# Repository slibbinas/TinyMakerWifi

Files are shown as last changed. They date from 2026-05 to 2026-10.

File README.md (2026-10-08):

# TinyMakerWifi

Modified and extended firmware for the open-source **TinyMaker** MSLA resin 3D printer. The main additions: **WiFi connectivity**, **OTA updates**, and **direct model upload from PrusaSlicer** - no more SD card shuffling.

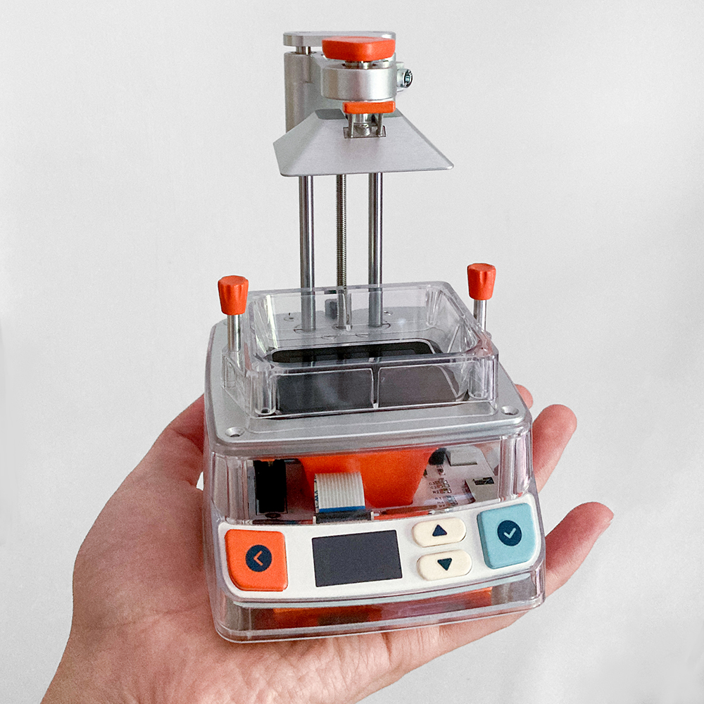
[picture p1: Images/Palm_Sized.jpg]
TinyMaker palm-sized resin 3D printer


🌐 **[tinymakerwifi.com](https://tinymakerwifi.com)** - the project site: what the firmware does, how to get started, community links and an *Open my printer* shortcut.

🧪 **[Live demo](https://tinymakerwifi.com/demo/)** - the real web dashboard driving a simulated printer: start a print, watch the 3D progress, poke through Settings. Nothing to install, no printer needed.

📖 **[Illustrated user manual](https://slibbinas.github.io/TinyMakerWifi/manual/)** - step by step from the first flash to Home Assistant, with screenshots and an FAQ. Also one tap away from the printer's dashboard (the *Manual* link in the header).

📝 **[Changelog](CHANGELOG.md)** - what each version added and who contributed it, in plain language.

💬 **[Feedback](https://tinymakerwifi.com/feedback/)** - what works, what doesn't, what's missing. Photos welcome, no account needed; the dashboard header links it too.

## Features

* **WiFi setup via captive portal** - no credentials in code, configured from your phone on first boot
* **Direct upload from PrusaSlicer** ("Send to printer" button) - the printer emulates the Prusa SL1 network protocol
* Automatic unpacking of uploaded `.sl1` / `.zip` files into the layer format the stock firmware expects (works with both PrusaSlicer and UVtools numbering). A model sliced for a different printer - layers wider than the 320 px screen - is refused with a *re-slice it for TinyMaker* message, on the printer and in the dashboard, instead of being started
* New **System** menu on the printer: WiFi Info (SSID, signal, IP, reset), **Advanced** settings, **Statistics**, firmware Update, About
* **Advanced menu on the printer** - screen timeout, dry run, the resin-tracking controls (Set VAT full, low-resin pause, warn threshold, ask-refill) and **WiFi / Web control on-off switches**, all without a computer *(contributed by [@Briadark](https://github.com/Briadark))*
* WiFi status indicator (green/grey dot) on the main menu
* **Model deletion from the printer** - long-press OK on a model in the Print menu
* **Import from SD card** - copy an `.sl1`/`.zip` onto the card and it shows up in the Print menu (in blue); press OK to convert it into a printable model. Works without any network, the archive is removed after a successful import
* **Lifetime print-hours & UV LED hours counters** - the System → Statistics screen shows total printing time and total LED-on time (the LED ages by lit time; dry runs don't count). Stored in NVS, survives firmware updates
* **Settings backup & restore** - one file holds every setting and the lifetime counters: download it, keep it on the SD card, and after a full USB reflash the printer offers to restore everything on first boot. The dashboard shows the SD backup's date, has a one-click **Restore from SD**, and can optionally **auto-backup to TinyMaker Connect** *(contributed by [@Briadark](https://github.com/Briadark))*
* **Boot update check** - shortly after WiFi connects at boot the printer checks for new firmware and offers *Install / Later* right on the screen (switchable) *(contributed by [@Briadark](https://github.com/Briadark))*
* **Boot animations** - pick the animation the printer plays at power-on (System → Advanced, or staged in the dashboard and applied with *Save config*), preview it with **Show** right on the printer's screen, install new ones one-click from the **Default library** or the community site, or **Shuffle** a random one each boot *(base contributed by [@Tann2019](https://github.com/Tann2019))*
* **Exposure calibration test** - cures an 8-bar test strip straight from the printer (System → Advanced), each bar a different exposure; no slicer or SD file needed
* **Clean Resin Vat** (Maintenance) - full-screen UV exposure cures a thin skin over the vat so debris lifts out in one piece (stock TinyMaker feature, kept and counted into LED hours)
* **Named resin profiles** - one resin, one recipe: layer height, both exposures, base and transition layers, all four lift settings, and the resin’s density with its weighing calibration. Switching resin is one press instead of ten fields. Four profiles are **built into the firmware** - two resins at both layer heights, `Fast fine` / `Fast draft` and `Slow fine` / `Slow draft` (so the list is never empty - no SD card, no network, after a factory reset). The two `Fast` profiles ship with a weighing calibration measured on this printer - a multiplier plus about 0.6 ml of film that stays on the plate each print - while the `Slow` pair starts uncalibrated until you weigh a print. A **library of ready-made profiles** can be installed from the picker; a “✓ tested by” badge means someone actually printed with that resin on this printer. Pick the resin from the dashboard’s main view, from Settings → Print, or at the machine under System → Advanced → Resin
* **Resin usage estimate** - press UP on the print preview to estimate the resin a model needs - shown in ml AND in vat fills (e.g. `12.4 ml = 0.8 VAT`; vat size adjustable 10–40 ml in Settings, default 15). Live ml is shown while printing
* **Resin level tracking** - the printer keeps an estimate of how much resin is left in the VAT, warns before starting a print with too little, and can optionally pause mid-print for a refill (see [Resin level & refills](#resin-profiles-level--refills))
* **Model preview in the dashboard** - click any SD model: the browser rebuilds the shape from the sliced layers and draws it in the **Model preview** card as a smooth, GPU-rendered 3D model (three.js, cached on the SD card - falls back to the built-in renderer without it), with a compact info line (layers, height, time, resin) and a quick `~ml` resin estimate - click it to run the exact scan. The card's title names the model it is showing and is a link back to it in the SD list - including while printing, when the title reads *Printing 42% · Tooth*
* **Slice in the browser** - the dashboard slices STL files itself, on by default: choose an STL (or drag it onto the slicer block), get supports and a raft, preview the result in 3D and 2D/UV, and send it to the SD card ready to print. The slicer module is fetched once, kept on the SD card (survives firmware updates, works offline afterwards) and every byte is verified against checksums the printer fetches over certificate-checked HTTPS
* **Safe model uploads** - uploads unpack into a temporary folder and replace the old model only after unpacking succeeds; a name conflict asks *Replace / Rename / Cancel* (PrusaSlicer re-uploads just replace) *(contributed by [@Briadark](https://github.com/Briadark))*
* **3D print progress** - while printing, the dashboard shows the same 3D view filling up in real time: the printed part in color, the rest as a ghost outline. Zero load on the printer (the browser renders from prefetched layers)
* **WiFi reset** - from the System menu, or by holding the BACK button while powering on
* **Web dashboard** - open the printer's IP in a browser: SD manager (upload - or drag an `.sl1`/`.zip` onto it - delete, start), live print status with pause/resume/stop and finish-time estimate, device config and a dry-run test mode - with a **light / dark / system theme**, a dismissible **Getting Started** checklist, contextual **?** help next to the tricky settings, an always-on **Model preview** card (remembers the last previewed model) and a **PWA manifest** so the dashboard pins to a phone's home screen with the project icon. While a print runs, the slicer and SD cards fold to their headers and stay locked until it ends *(initial version contributed by [@Briadark](https://github.com/Briadark))*
* **Power-loss resume** - a checkpoint on the SD card lets the printer pick a print back up after an outage instead of starting over, or safely lift the plate off a stuck print (up only, never into the vat). Answer the prompt at the printer **or from the dashboard on your phone** - a first for a resin printer in this class *(checkpoint engine contributed by [@Tann2019](https://github.com/Tann2019))*
* **MQTT / Home Assistant** - optional integration with auto-discovery: print state, layers, resin used, **resin left + low-resin alert**, run/remaining time as HA sensors
* **Telegram, WhatsApp or Discord notifications** - the printer messages you when a print **finishes** (with time and resin used), **pauses for low resin**, is **canceled**, or when **power comes back** after an outage interrupted a print. Pick one channel: a Telegram bot, WhatsApp through the free CallMeBot gateway, or a Discord channel webhook - each with inline **?** setup help and a *Send test* button. *(Telegram is tested daily; WhatsApp and Discord ship untested - they ride on your own CallMeBot key or channel webhook, so the only test that proves anything is yours. Reports welcome, working or not.)*
* **TinyStatus watch app** - a separate Wear OS app, [TinyStatus](https://github.com/slibbinas/TinyStatus), puts time left, the layer, resin left and a progress ring on your wrist and watch face, and buzzes when a print ends or the resin runs low. It only reads - see [On your wrist: TinyStatus](#on-your-wrist-tinystatus)
* **Anonymous usage ping and crash reports** (optional) - once per firmware version the printer sends a one-way hash of its MAC address, the firmware version and the lifetime print hours, so we know how many printers are out there. If it restarts unexpectedly or dies in the middle of a print, it also sends a short crash report: the same hash, the firmware version, why it restarted, the layer the print stopped at and roughly when, and - after a crash - the program addresses where it happened plus a fingerprint of the exact firmware build, so the fix can find the line. No models, settings or network details, ever - switch both off under Settings → Network → *Anonymous usage ping*
* **Firmware updates over WiFi** - self-update from the printer (System → Update) or from the dashboard's **Settings → Update** pane (install latest, pick **any version** from a list, or upload a file). Self-update follows the stable channel; betas are offered only in that version list, so no printer installs one by itself. PlatformIO OTA for developers. Flashing is blocked while printing.
* Everything is switchable: WiFi and Web control can be turned off right on the printer (System → Advanced), and build switches still let developers compile the original, network-free firmware from the same code base

## Screens

The small status display drives the whole UI - first-boot WiFi setup, wireless upload, resin estimate and guarding, device toggles, and self-update:

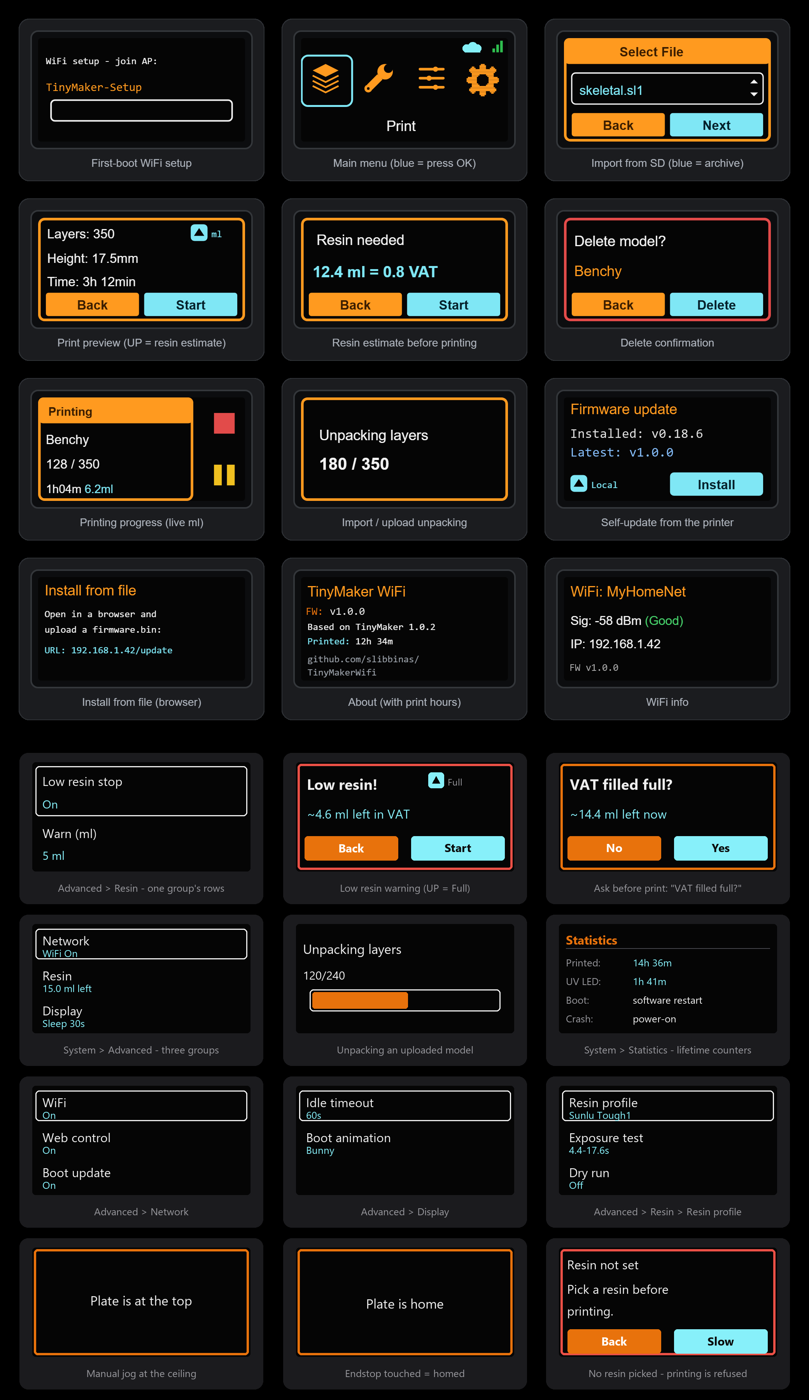
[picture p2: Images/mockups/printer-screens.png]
TinyMaker WiFi - printer UI screens


## Hardware

Stock TinyMaker electronics - **ESP32-WROOM-32E-N4** (4 MB flash, no PSRAM). No hardware modifications required; WiFi is already on the module.

## Installing the firmware

Three ways to get the firmware onto the printer - the first is by far the easiest.

### Method 1: Web flasher (recommended)

**[connect.tinymakerwifi.com/flash.php](https://connect.tinymakerwifi.com/flash.php)** flashes the latest release straight from your browser - nothing to download or install *(contributed by [@Briadark](https://github.com/Briadark))*:

1. Connect the printer to your computer via USB.
2. Open the web flasher in **Chrome or Edge** (they support Web Serial; Firefox/Safari don't).
3. Click **Connect** and select the printer's serial port (unsure which? unplug/replug the USB cable and watch which entry appears).
4. Flash - the tool fetches the latest release itself. Power cycle the printer when it finishes.

If your computer does **not** recognize the printer over USB, install the CH340 driver from the `Driver` folder of this repository (`CH341SER.EXE`), then try again.

#### Flashing fails with `ERROR: Timeout`?

If the flasher connects, downloads the firmware and then dies partway through **Writing firmware-full.bin**, the transfer speed is almost always the culprit - not the browser:

1. **Lower the baud rate.** The **Baud rate** dropdown on the flasher page defaults to `921600`. Set it to **115200** and flash again. It takes a few minutes instead of ~30 seconds, but it tolerates marginal cables and USB-serial chips far better.
2. **Swap the USB cable.** Charge-only cables and cables with thin data lines are the second most common cause. Use a short, known-good data cable.
3. **Plug straight into the computer**, not through a hub, dock, monitor or keyboard port.
4. **Update the CH340 driver** (see above) - an old Windows-bundled driver produces exactly this symptom.
5. **Several ports in the picker?** Unplug the printer, reopen the port picker, plug it back in, and choose the entry that appears.

Still stuck after all five? Open an [issue](https://github.com/slibbinas/TinyMakerWifi/issues) with the flasher log and the baud rate you used.

### Method 2: Already running TinyMakerWifi? Update over WiFi

No USB needed - use `System → Update` on the printer or the dashboard's **Settings → Update** pane. See [Wireless Firmware Updates](#wireless-firmware-updates).

### Method 3: Manual flashing (fallback & developers)

Download the latest **`firmware-full.bin`** from the [Releases](https://github.com/slibbinas/TinyMakerWifi/releases) section of this repository.

> ⚠️ **Which file do I need?** Releases contain two files and they are NOT interchangeable:
>
> | File | Used for | How |
> |---|---|---|
> | **`firmware-full.bin`** | **First-time USB flashing** (this section) | USB flash tool, address **`0x0`** |
> | `firmware.bin` | Wireless updates **only**, after this firmware is already installed | Browser, `http://tinymaker.local/update` |
>
> Flashing `firmware.bin` over USB will **not** work correctly: it lacks the bootloader and partition table, so the printer either won't boot (if flashed at `0x0`) or OTA updates will be broken (if flashed at `0x10000` over the stock firmware).

**Option A: generic web esptool** - [https://esptool.spacehuhn.com/](https://esptool.spacehuhn.com/) in Chrome/Edge: click **Connect**, pick the port, **remove all pre-filled entries**, click **ADD**, upload your **`firmware-full.bin`** with its address set to **`0`**, then **Program** and power cycle.

**Option B: Espressif Flash Download Tool (Windows)** - if you prefer the official desktop tool:

1. Get **`flash_download_tool.zip`** from the `Flash_Installer` folder of this repo (or the official [Espressif Flash Download Tool](https://docs.espressif.com/projects/esp-test-tools/en/latest/esp32/production_stage/tools/flash_download_tool.html) page). **Extract the ZIP fully before running.**
2. Run the extracted `flash_download_tool_xxx.exe`.
3. In the "Download Tool" window, select **ESP32** and **Develop** mode.
4. Configure the settings **exactly** as follows (wrong settings are the most common cause of a non-booting printer):
    * **SPI Speed:** 40 MHz
    * **SPI Mode:** DIO
    * **Flash Size:** 32 Mbit (4MB)
5. Click the three dots `...` next to the first row and select **`firmware-full.bin`** (not `firmware.bin`!).
6. In the address field next to the file, enter **`0x0`** (zero - not `0x10000`).
7. Ensure the checkbox on the left of the file path is **checked** - without it the tool flashes nothing and still reports success.
8. Select the correct **COM port**, click **START**, and power cycle the printer when it says "FINISH".

Note: the first boot after flashing may take a few seconds longer than usual, and the printer will start the `TinyMaker-Setup` WiFi access point (see below). Printer settings (exposure, layer height, etc.) reset to factory defaults.

## First WiFi setup

1. Power on the printer. On first boot it starts a **`TinyMaker-Setup`** access point.
2. Connect to it with your phone - a captive portal opens automatically (or browse to `http://192.168.4.1`).
3. Select your home WiFi network and enter the password.
4. The printer connects and briefly shows its IP address; credentials are stored, so next boots connect automatically (~5 s) - animated signal bars on the boot screen turn green when connected. If the saved network is unreachable, the printer simply boots in offline mode after 15 s - printing from SD works as always.

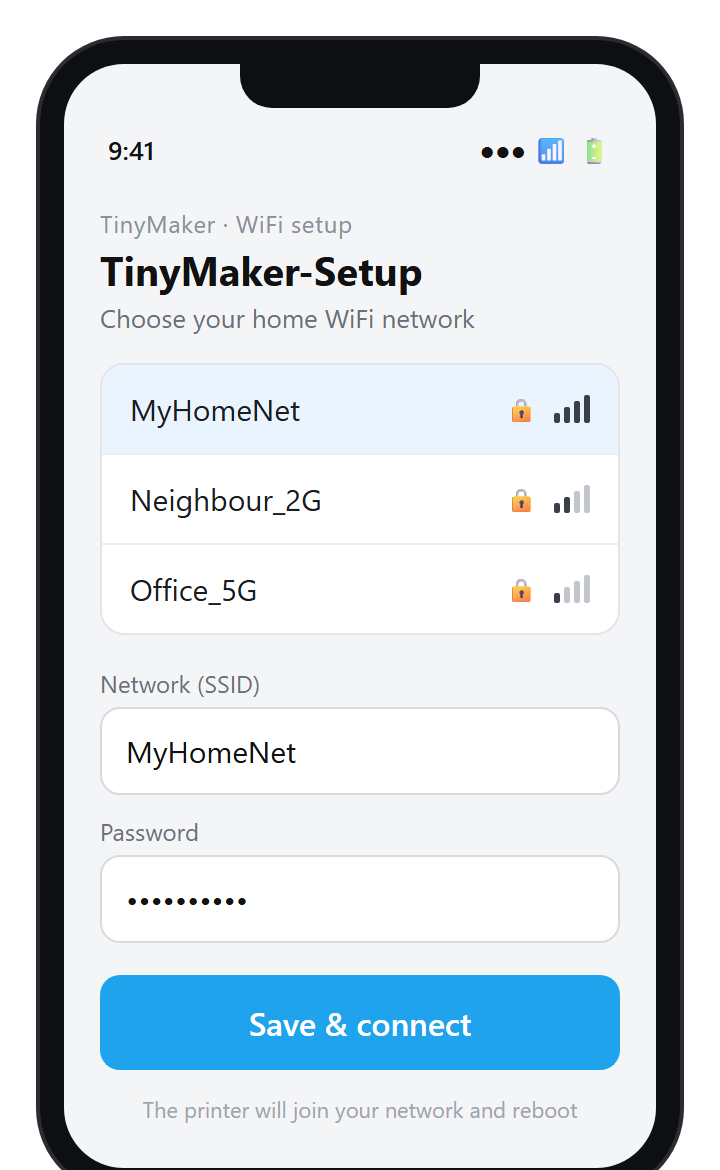
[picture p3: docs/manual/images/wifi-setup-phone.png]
TinyMaker-Setup captive portal as seen on a phone


WiFi status, signal strength and IP are always visible under **System → WiFi Info**.

### Resetting WiFi

Two ways to erase the stored credentials (e.g. when moving the printer to another network):

* **From the menu:** System → WiFi Info → press OK → confirm. The printer erases the credentials, reboots and starts the `TinyMaker-Setup` portal again.
* **Emergency reset:** hold the **BACK** button while powering the printer on. Use this if the printer keeps trying to connect to an old network and you can't reach the menu in time.

## PrusaSlicer setup

1. Import the TinyMaker printer profile (`TinyMaker.ini`, in this repo) via *File → Import → Import Config*.
   **Then save each of the three presets** - click the floppy-disk icon next to *Print settings*, *Material* and *Printer* and accept the names. Imported presets are temporary until saved, so without this step PrusaSlicer forgets the printer every time you close it, and you start over.
2. Add a **physical printer**: click the cog icon next to the printer profile → *Add physical printer*:
   * **Name:** anything (e.g. `TinyMaker WiFi`)
   * **Hostname, IP or URL:** `tinymaker.local` (or the printer's IP shown in System → WiFi Info)
   * **API Key:** any text (not verified)
   * Note: The printer emulates the Prusa SL1 network protocol.
3. Click **Test** - it should report a successful connection (printer must be on and connected to WiFi).
4. Slice and press **Send to printer**. The printer shows *Receiving → Unpacking → Model ready*, and the model appears in the **Print** menu.

<p>
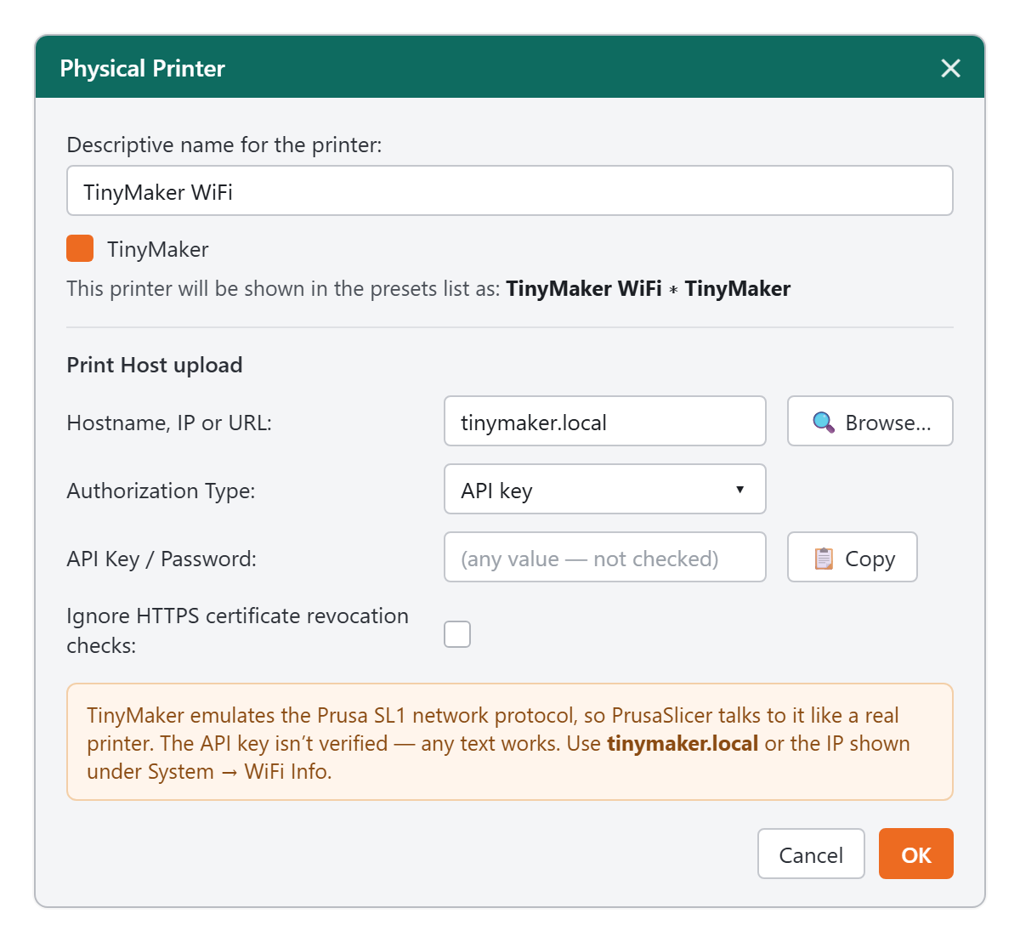
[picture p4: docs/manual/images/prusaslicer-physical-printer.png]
PrusaSlicer: add a physical printer pointing at tinymaker.local with API key auth
  
  &nbsp;
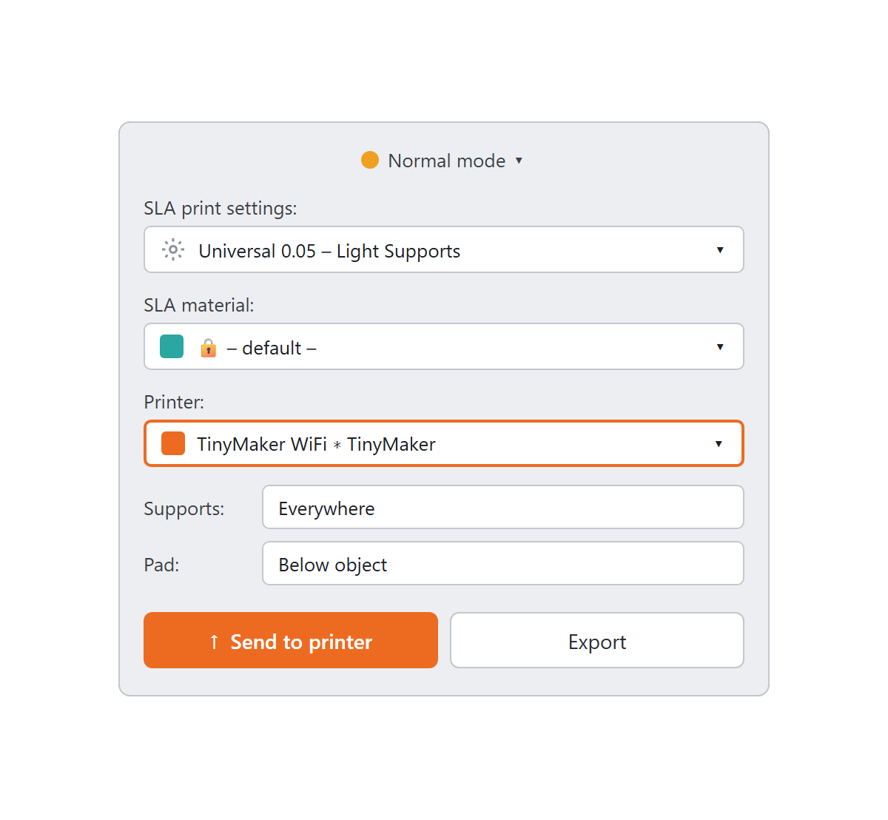
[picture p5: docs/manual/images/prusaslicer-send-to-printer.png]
PrusaSlicer: select the TinyMaker WiFi printer and press Send to printer
  
</p>

**Always slice with the 0.05 mm profile.** Unlike FDM, the printed layer height is set **on the printer** (Settings → Layer Height), not by the sliced file - the file is just a stack of 0.05 mm images, and at the 0.10 mm printer setting the firmware takes every other image. Maximum model size: 1200 layers = 60 mm. If prints come out **flat or the wrong height**, check that PrusaSlicer's *Print settings* still show **0.05 mm** - an update or the wrong preset can silently reset it, and the printer can't detect it from the file.

## Slice in the browser

No slicer installed, and nothing to install: the dashboard slices STL files itself, and since
0.17.6 it is on from the start - the **STL slicer** card is right there on the dashboard. (It
can be switched off under Settings → Network → *STL slicer in the dashboard*.) Choose an STL, let it stand the right way up, then press **Slice**.

Two switches decide how the slicer places the part on its own. **Fit by:** *flat* lays it on
its widest side, *supports* searches for the rotation that needs the fewest supports, the way
PrusaSlicer does. **Size:** *keep* leaves your size and scales down only when the part does not
fit, *max* makes it as large as the plate allows, up to 300 %. The **Fit** button on the 3D view
puts the part back the way the two switches say; **Lay flat**, **Flip over**, **Tilt 90** and
**Rotate 90** are there when you want to decide yourself.

Below sit six more settings, and **Reset to defaults** puts them all back (Fit by and Size
included): **Supports** (regular or tree), **Strength**, **Placement**, **Tip**, **Raft layers**
and **Smoothing**.
The raft is counted **in layers, not millimetres**. The file is always sliced at 0.05 mm and
the printer decides how many of those images to expose, so the same setting means different
millimetres at a different layer height. The default is **3 layers**; the choice is 2, 3 or 6.
One layer is not offered any more - the pad does not bond to the part at all. Measured here:
a printed pad comes out about 0.15 mm thicker than asked, so 3 layers lands on the ~0.3 mm a
PrusaSlicer plate gives and lifts off with a spatula without force. A thicker raft costs
resin, not time - unless the part is lifted off the plate: then it adds layers too.

You get the result before anything is sent anywhere: the part on its raft in 3D, layer by
layer in 2D, and the numbers that matter underneath - size, triangles, layer count, supports
and the resin estimate. **Send to printer** then puts it on the SD card, ready to print;
**Discard** throws it away and costs nothing.

The slicer is a **module the printer keeps on its own SD card**: fetched once from our GitHub
Pages, verified byte-for-byte against checksums, and used from the card afterwards - so it
works with no internet and survives firmware updates. Everything is sliced at 0.05 mm, the
same as every other model here.

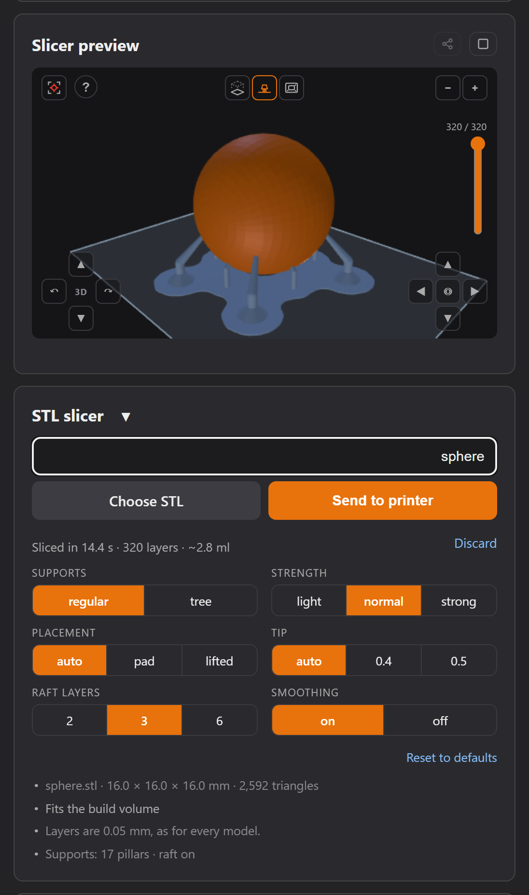
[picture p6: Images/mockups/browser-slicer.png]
A model sliced in the browser: the preview shows the part in orange standing on its raft with 180 support pillars in blue, and the slicer card reports the time, the layers, the resin and the supports it added


## Importing models from the SD card

No network? Copy an `.sl1` or `.zip` (exported by PrusaSlicer/UVtools) into the **root** of the SD card. It appears in the **Print** menu in **blue** among the models - press **OK** to convert it (progress is shown). When done, the new model appears in the list and the archive is deleted from the card. Long-press OK on a blue entry deletes the archive without importing.

## Deleting uploaded models

In the **Print** menu, **press and hold OK for ~1.5 seconds** on a model - a *Delete model?* confirmation appears (release the button first, then **OK = Delete**, **Back = No**). Deletion removes the whole model folder from the SD card and shows a progress bar (large models take a while - hundreds of layer files). A short OK press starts printing as usual.

## Web dashboard

Open the printer's IP address in any browser for the full dashboard *(initial version contributed by [@Briadark](https://github.com/Briadark))*: live print status and controls, SD card management with one-click start/import, device settings, backups and firmware updates - all in tabs styled to match the printer's UI.

In a narrow window - a phone, or half a screen - everything is one column:

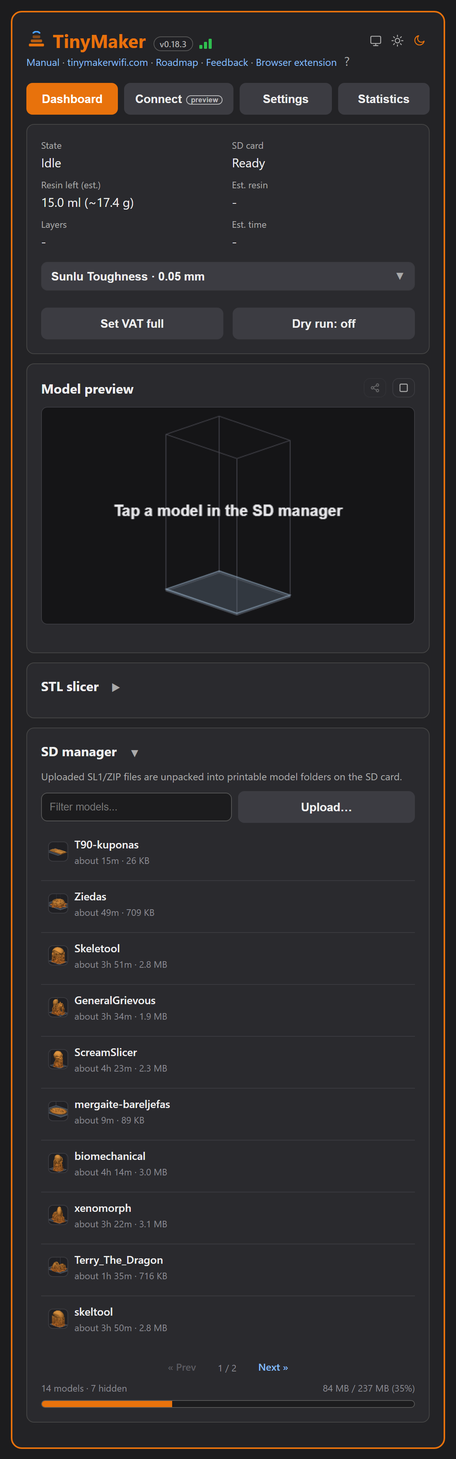
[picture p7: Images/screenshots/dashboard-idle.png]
The dashboard in a narrow window: one column, with the status card, the model preview and the SD manager stacked


On a desktop-sized screen it spreads into two columns:

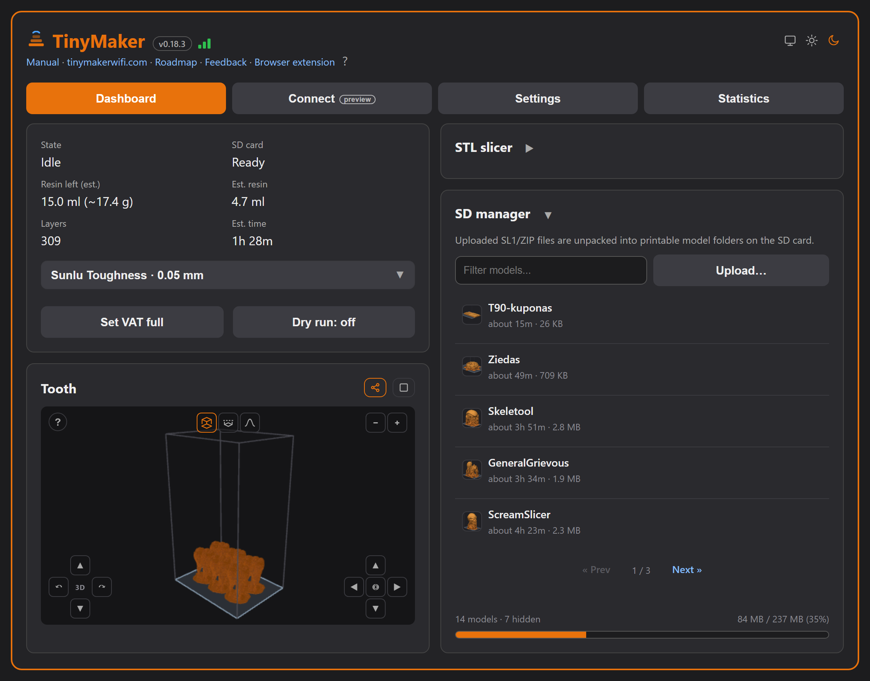
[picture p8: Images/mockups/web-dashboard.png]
The dashboard on a wide screen: two columns, with status and model preview on the left, the STL slicer and SD manager on the right


While a print runs, the status card counts the current phase down next to its name - *Curing · 9s* - and a small dot says whether the printer answered just now or is mid-move. That matters on this hardware: one ESP32 drives the screen, the motor, the UV LED and the web server off a single SD card, so the dashboard is served in the gaps between layer moves. A pause of a few seconds with an amber *syncing* mark is the printer working, not the page hanging. How long the dashboard waits follows the print (the longest exposure plus 10 seconds); if your phone or laptop reaches the printer through a slow link such as a WiFi extender, give it more time under **Settings → Network → Wait while printing** - the value is kept in that browser only.

### 3D preview & live print progress

Every model on the SD card can be previewed in 3D - the browser rebuilds the shape from the sliced layers (the printer only streams a few dozen small files) and draws it inside the build-volume box. Start the print from the dashboard and the same view turns into a **live progress render**: the printed part fills in with color, the unprinted rest stays a ghost outline. It costs the printer nothing while printing.

There is no mesh to render - the model reaches the printer already sliced into images, so the shape is rebuilt from the layers themselves. The smooth surface comes from three.js on the GPU; the library is fetched once and then lives on the SD card, so the preview keeps working with no internet. Without the library (or on a browser without WebGL) a built-in canvas renderer takes over: only the surfaces the camera can actually see are drawn, each shaded from a normal estimated out of its neighbourhood, which is what makes blocky voxels read as a rounded object.

A real print in progress - a plate of teeth with supports, rendered live in the build-volume box:

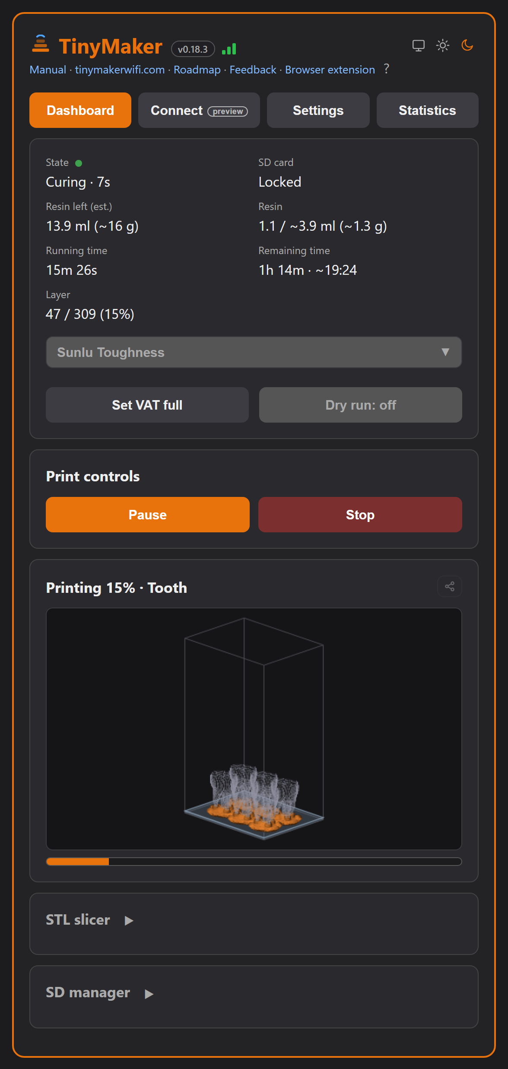
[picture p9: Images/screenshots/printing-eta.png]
Real dashboard screenshot while printing: status with finish-time estimate, print controls and the live 3D print progress render


## Advanced menu (WiFi and Web control switches)

**System → Advanced** on the printer *(contributed by [@Briadark](https://github.com/Briadark))* holds the device toggles - OK changes a value, Back returns:

Since 0.16 the items sit in **three groups** - Network, Resin and Display - so the list stays
short at every step, and each group row shows its own state at a glance (`WiFi On`,
`15.0 ml left`, `Sleep 60s`).

**Network**

| Item | What it does |
|---|---|
| **WiFi** | **On/Off - the whole network** (web, PrusaSlicer upload, MQTT, self-update) |
| Web control | On/Off - browser **actions**. Off = the dashboard turns view-only (watch, but no print control, SD changes, uploads or firmware updates) |
| MQTT | On/Off (shown once MQTT is configured in the dashboard) |
| Boot update | On/Off - whether the printer checks for newer firmware shortly after it connects |

**Resin**

| Item | What it does |
|---|---|
| Resin profile | Steps through the installed profiles and applies the one shown - the whole recipe for that resin |
| Set VAT full | Press after a **full** refill - restarts the level estimate from a full VAT; it does not measure what you poured |
| Low resin stop | On = mid-print, at *Stop (ml)*, the printer finishes the layer, lifts and pauses for a refill. On by default: below the stop level the VAT floor goes dry |
| Stop (ml) | The level that stops the print: 3 - 4 - 5 - 6 - 7 - 8 ml (OK cycles), default 4. Three is this VAT's measured floor, not a preference |
| Warn (ml) | The earlier heads-up, on the screen and on your phone: 5 - 6 - 7 - 8 ml, default 5. Keep it above the stop level |
| Ask refill | On = every print starts with a "VAT filled full?" question (Yes resets the estimate to a full VAT, so answer yes only after a full refill) |
| Power resume | On = the printer checkpoints as it prints and offers to resume after a power cut |
| Resume mode | **Balanced** checkpoints every 800 ms of plate movement, **Precise** every 400 ms |
| Pause lift | How high the plate rises when you pause to look at the print: 20-40 mm in 5 mm steps |
| Exposure test | Cures an 8-bar calibration strip around your Regular exposure - resin in the vat, no build plate |
| Dry run | Test prints without UV - motion and display only (the UV stays off *everywhere*, the vat-cleaning cycle included) |

**Display**

| Item | What it does |
|---|---|
| Idle timeout | Blank the status screen after 30 s...10 min of inactivity (Off = never). Only while idle - never mid-print |
| Boot animation | Which animation plays at power-on |

How the network switches behave:

* **WiFi Off** makes the printer fully offline, like the original firmware. Toggling WiFi asks *"Reboot now?"* - OK reboots and applies it immediately, Back applies it on the next power-up. Everything network-related disappears from the menus until WiFi is back on - **turning it back on is done right here (System → Advanced → WiFi)**, no reflash or reset needed.
* **Web control Off** makes the dashboard **view-only**: anyone on the network can still open it and watch the print (status, layers, resin left, SD contents, model details), but every action - print stop/pause, SD delete/upload, resin estimate, settings, Set VAT full, firmware updates - is disabled with a clear banner. PrusaSlicer/UVtools "Send to printer" and MQTT/Home Assistant keep working. Turning it back on is done on the printer (System → Advanced), since the settings form is among the things it locks.
* If WiFi is off and you open **System → Update**, the printer offers to enable WiFi temporarily just for the update.
* WiFi and Web control are also in the dashboard's Settings tab (with a confirmation - unchecking Web control locks you out of settings until it is re-enabled on the printer, and turning WiFi off from the browser reboots the printer).

Both switches default to **On**, and stay On after upgrading from an older version - nothing changes until you change it.

## Resin profiles, level & refills

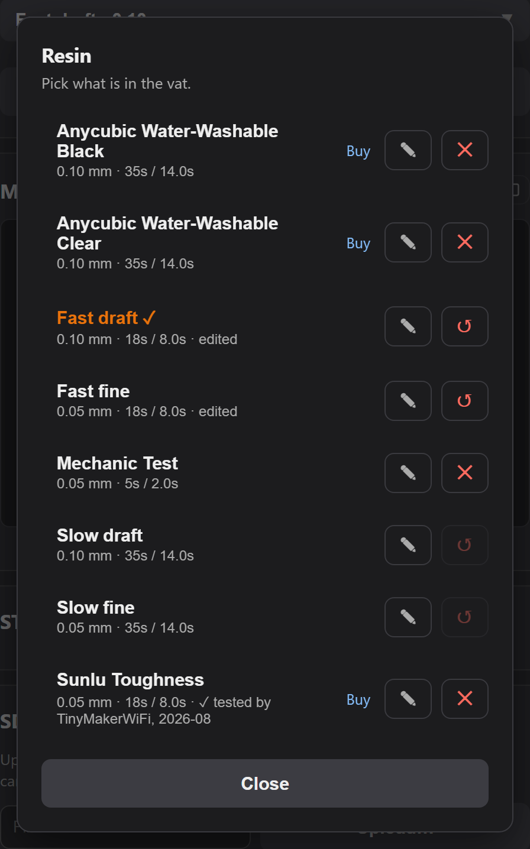
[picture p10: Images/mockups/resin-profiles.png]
The resin picker: built-in and installed profiles, one marked tested by with a Buy link, and a line offering ready-made profiles to install

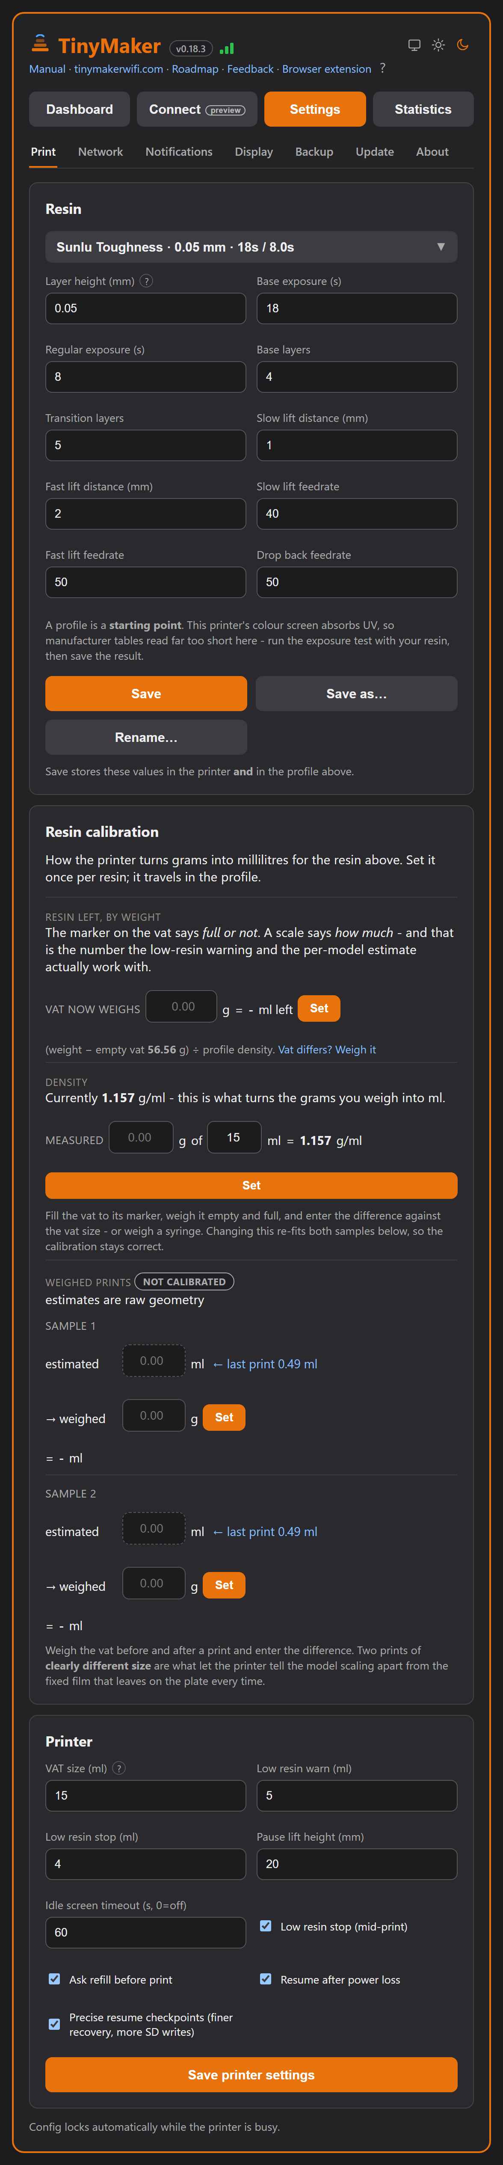
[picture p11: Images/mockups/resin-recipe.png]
Settings, Print tab: the selected profile with its whole recipe - layer height, exposures, layers and the four lift settings - then Save, Save as and Rename, and the resin calibration by weight


The printer has no resin sensor - instead it **keeps count**: every printed layer's cured volume (the same white-pixel estimate used for the ml counter) is subtracted from the VAT level. The estimate survives reboots and firmware updates.

* **"Resin left (est.)"** is shown on the dashboard; in Home Assistant it appears as a *Resin left* sensor plus a *Resin low* alert you can automate notifications on.
* **After a full refill**, tell the printer: **System → Advanced → Set VAT full** on the printer, or the **Set VAT full** button on the dashboard - it works while printing too. The estimate restarts from a **full** VAT (your VAT size setting): it does not measure what you poured, so fill it to the top. Pouring less leaves the printer believing it has more resin than it does.
* **Ask refill** (default On): every print begins with a *"VAT filled full?"* question - on the printer (OK = yes / Back = no) and in the browser - so the estimate stays honest even if you forget the button. Tidy users can turn it off (System → Advanced or dashboard Settings); the low-resin warning screen then still offers **UP = Full** as a shortcut.
* **While printing** the dashboard shows resin like layers: `used / ~total ml` (total = the fresh estimate when you ran one, otherwise a running average) plus *Resin left (est.)* in the VAT.
* **Before a print starts**, if the level is at/below the warning threshold (or a fresh ml estimate says the model needs more than what's left), the printer shows **"Low resin!"** with the numbers - Start anyway or Back. Starting from the browser asks the same in a dialog.
* **Low resin pause** (default On): mid-print, when the level drops to the threshold, the printer finishes the layer, lifts and pauses showing **"Fill VAT full!"** - do a full refill, press Set VAT full, then resume. Resume stays locked until the refill is marked, and only Stop works meanwhile; on the printer itself, confirming *"VAT filled full?"* marks it and resumes. The threshold (`Stop (ml)`, 3–8 ml, default 4) is set on the printer (System → Advanced) or in the dashboard's Settings tab.
* **Roughly 4 ml of every filling cannot be printed with.** The VAT is 42 × 52 mm inside, so a millimetre of resin is about 2.2 ml and a full 15 ml VAT is under 7 mm deep. Poured resin stops covering the whole floor at about 4 ml, and it clings to the walls, so the middle can open a dry patch a little above that. That is why the stop level cannot be set below 3 ml, and why a 15 ml VAT gives about 11 ml of printing per filling.

> ⚠️ It is an **estimate**, not a measurement - it doesn't account for resin sticking to models or drips, so treat it as a planning aid and glance at the real VAT now and then. Refills you don't confirm with "Set VAT full" won't be counted.

## On the browser toolbar: TinyMaker status (Chrome extension)

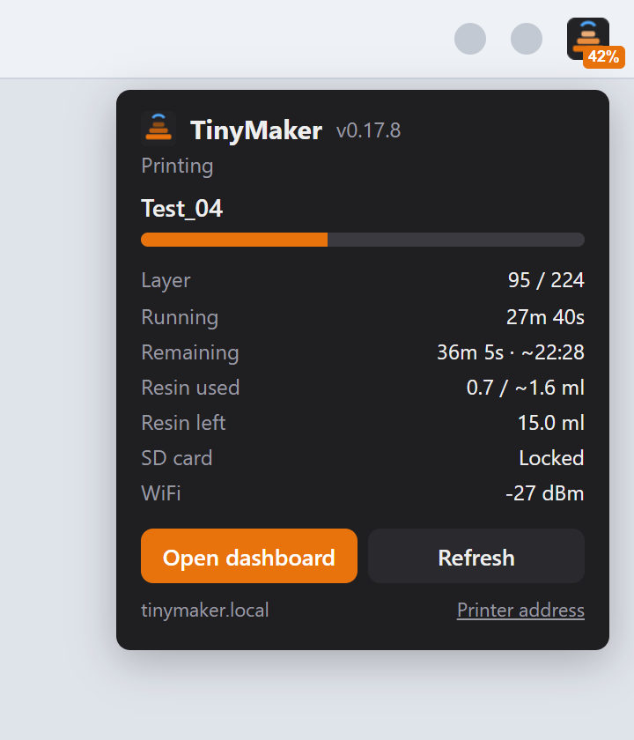
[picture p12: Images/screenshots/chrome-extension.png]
TinyMaker status extension: 42% on the toolbar icon and the popup with the print's layer, times and resin


A small Chrome extension puts the printer on the browser toolbar: the icon shows the print
progress (`42%`), `II` when paused, `SD` while the card is busy, a tick when a print has just
finished and `!` when the printer does not answer. Click it for the state, model, layer,
time left (with the finishing time), resin used and left, and a button that opens the
dashboard - or switches to it, if it is already open in a tab. It only reads the printer's status once a minute - it never changes anything.

**[Install it from the Chrome Web Store](https://chromewebstore.google.com/detail/tinymaker-status/bhfjpfjkhopfnfpapgahmaipdgmajlde)** - one click, and Chrome keeps it updated.

1. **Add to Chrome.** Its options page opens by itself.
2. Enter the printer's address - the same one you open the dashboard with (the printer shows
   it on the idle screen and under **System -> WiFi Info**), or `tinymaker.local` - and press
   **Save**. Chrome asks to let the extension read that one address: **Allow**.
3. Pin it so the icon stays on the toolbar: the puzzle icon at the top right -> the pin next
   to **TinyMaker status**.

Had the earlier zip installed by hand? Remove it in `chrome://extensions` first, otherwise you
get two icons. For the first months Chrome may call it *not trusted by Enhanced Safe Browsing* -
every new developer starts like that, and it clears on its own. Tested in Chrome; Edge has not
been tried yet.

## On your wrist: TinyStatus

<p align="center"><a href="https://github.com/slibbinas/TinyStatus">TinyStatus on a Wear OS watch showing the printer's status</a></p>

**[TinyStatus](https://github.com/slibbinas/TinyStatus)** is a Wear OS app that shows what
this printer is doing without reaching for a phone: time left, which layer, how much resin
is still in the VAT, and a progress ring. It can watch a print in the background and buzz
your wrist when the print ends or the resin runs low, and it can put those numbers on your
**watch face** as complications.

It is **not firmware** - it installs on the watch, not on the printer, and it only reads.
It sends no commands, so it cannot start, pause or cancel anything.

* **Download:** [latest release](https://github.com/slibbinas/TinyStatus/releases/latest)
  (`tinystatus-<version>.apk`). Not on Google Play, so it is **sideloaded** - the release
  notes walk through it from a phone (no computer needed) or over `adb`.
* **You need:** a Wear OS 4+ watch, the watch and the printer on the same Wi-Fi, and
  firmware **0.16.2 or newer** - that is what it has been tested against. Two fields
  arrive with **0.17.0**, and without them the app gets less precise rather than
  breaking: telling a cancelled print apart from a finished one falls back to the state
  code alone, and the low-resin warning uses the default 5 ml instead of the level you
  picked.
* **Several printers:** up to four by IP, swipe sideways to switch.
* **What it costs the printer:** `GET /api/status` every 5 s while the app is open, and
  nothing at all when it is closed - unless background watching is on, and then every
  30 s to 10 min (your choice) **only while a print is running**, stopping by itself
  20 minutes after it ends. `/api/config` is read once a day. No writes.

It lives in its own repository with its own releases, because it is an Android project and
this one is PlatformIO. If you are building something else against the printer, the API it
uses is documented in [docs/api.md](docs/api.md) - and the fields it reads are listed there
as a known consumer, so they will not be renamed out from under it.

## Wireless Firmware Updates

> 🔒 Firmware flashing is **blocked while the printer is printing**, and the web paths require **Web control** to be on. (Model upload from PrusaSlicer is separate - it works any time.)

Three ways to update:

* **On the printer (self-update, no computer):** `System → Update` shows the **installed** version and checks GitHub for the **latest**. If a newer one is available, the `Install` button lights up - press **OK** and the printer downloads and flashes it itself over WiFi.
* **From the dashboard - the Update tab:** shows installed vs latest with an **Install latest** button, a **version picker** (install any released version, downgrades ask for confirmation) and **Choose & flash…** for a `firmware.bin` file from [Releases](https://github.com/slibbinas/TinyMakerWifi/releases) or a local build.
* **For developers:** PlatformIO OTA - open `System → Update` on the printer (this path keeps the strict screen gate), then select the `env:tinymaker-ota` environment and Upload goes over WiFi.
* **The browser slicer updates separately.** As long as the slicer is on, the same Update tab holds a **Slicer module** card - the version on the printer’s SD card vs the latest published, with its own install button and version picker. A slicer update copies a few megabytes to the card; the printer never reboots for it, and a running print is never interrupted.

Every release carries our own signature. Before an update from the internet is installed, the printer checks that signature against a key built into its firmware and activates the download only if it matches byte for byte - so it no longer matters which certificate GitHub shows in your region or what the printer's clock says. If the check fails, nothing is installed and the printer says the update was refused. **Choose & flash…** (a file you pick) and USB flashing still work.

Do not power off during an update - and don't worry too much either: the dual OTA partition keeps the previous firmware if the update fails.

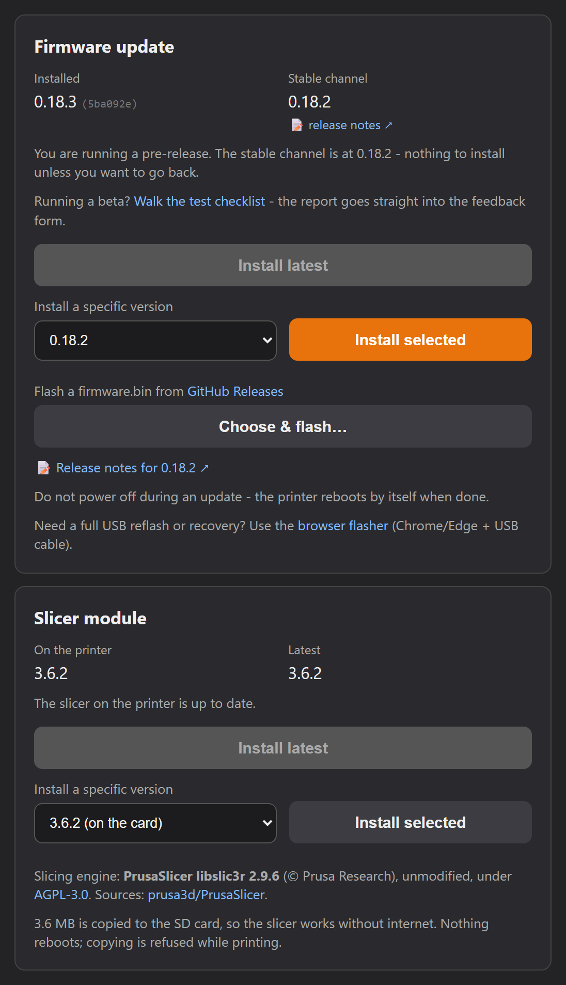
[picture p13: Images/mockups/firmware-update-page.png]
The dashboard Settings → Update pane: installed version vs the stable channel, version picker, firmware.bin upload and the Slicer module card


> The self-update needs the latest `firmware.bin` + a `version.txt` hosted on GitHub Pages. See [`Firmware_Hosting/`](Firmware_Hosting/) for the one-time setup and per-release steps.

## Building from source

Requirements: [VS Code + PlatformIO](https://platformio.org/).

1. Clone this repo.
2. Unpack the four vendor-verified libraries from `Firmware/Libraries/*.zip` of the original project into the `lib/` folder: `AccelStepper` (1.64), `Arduino_GFX` (1.2.0), `PNGdec` (1.0.1), `SdFat` (1.1.2). **Do not use newer versions from the registry** - the APIs changed.
3. `pio run` - the platform (`espressif32@6.5.0`, Arduino core 2.x) and the network libraries (WiFiManager, unzipLIB) are fetched automatically. Do not upgrade to Arduino core 3.x.
4. First flash goes over USB (`env:tinymaker`, CH340 serial); after that OTA works (`env:tinymaker-ota`).

Build switches at the top of the main `.ino` - **developers only**. To simply
turn WiFi off, use **System → Advanced → WiFi** on the printer instead; the
compile-time switch exists for building a binary with no network code at all:

```cpp
#define ENABLE_NETWORK       1   // 0 = original firmware behavior, no network code compiled in
#define ENABLE_SERIAL_DEBUG  1   // 0 = no serial output
```

## Support this project

If you find this project useful and want to support my work, you can [buy me a coffee via PayPal](https://paypal.me/Sidlauskas?locale.x=en_US&country.x=LT).

The dashboard asks once, too. After the third print that ran to the end with the UV on, a small dialog says thank you and offers a few amounts - each an ordinary link to that PayPal page - or **No thanks**. It is shown once per printer and never again, whatever you press; the printer never learns whether you paid. Failed prints and dry runs do not count.

The **Buy** links next to resin profiles are affiliate links: the shop pays this project a small share, at no extra cost to you. The dashboard says so next to them.

## Credits & Acknowledgements

* **The browser slicer's engine** - **PrusaSlicer's `libslic3r` 2.9.6** (© Prusa Research a.s.), compiled to WebAssembly from the **unmodified** upstream sources ([tag `version_2.9.6`](https://github.com/prusa3d/PrusaSlicer/tree/version_2.9.6), commit `b028299`) and used under the **[GNU AGPL-3.0](https://www.gnu.org/licenses/agpl-3.0.html)**. The rest of TinyMakerWifi remains MIT-licensed - the two are separate programs shipped side by side.
* **Original project:** [TinyMaker-Open-Source-3D-Printer](https://github.com/TinyMaker3D/TinyMaker-Open-Source-3D-Printer)
* **Original authors:** TinyMaker3D Team

## License

This project retains the original dual licensing of the TinyMaker3D project:

* **Firmware:** MIT License
* **Hardware:** CC BY-NC-SA 4.0

See `LICENSE.md` for full details and copyright notices.

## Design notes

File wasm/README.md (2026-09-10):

# libslic3r SLA naršyklėje (WebAssembly)

Čia gyvena receptas, kaip **tikrą PrusaSlicer atramų ir rafto variklį**
sukompiliuoti į WebAssembly ir paleisti naršyklėje - be serverio, be diegimo,
viskas vartotojo kompiuteryje.

Kodėl to reikia: mūsų pačių rašomas JS portas (`web/lib/sla/`) buvo įstrigęs
ties dviem dalykais - salų sėja (reikalauja Voronoi, ~8000 eilučių) ir greičiu
(biustas 285 s). Sukompiliavus originalą abu klausimai atkrenta savaime.

## Kaip paleisti

```bash
bash wasm/build.sh          # viskas nuo nulio (pirmą kartą ~40 min)
bash wasm/build.sh link     # tik perlinkuoti, kai pakeistas bridge.cpp
node /c/PIO-build/wasm-build/sla.js modelis.stl 0.05
```

Reikia `git`, `python` su `pip` ir `bash`. Visa kita (Emscripten, cmake, ninja,
PrusaSlicer šaltiniai, Eigen, CGAL, NLopt, qhull) skriptas parsisiunčia pats.

## Kas čia yra

| failas | kam |
|---|---|
| `build.sh` | visas receptas nuo tuščios mašinos iki `sla.wasm` |
| `bridge.cpp` | tiltas: kviečia SLA grandinę ta pačia tvarka kaip `SLAPrint`, su mūsų profilio parametrais |
| `sources.txt` | kurie `libslic3r` failai reikalingi SLA keliui (FDM dalis atmesta) |
| `shims/` | pakaitalai bibliotekoms, kurių naršyklėje nereikia (žr. žemiau) |

## Pakaitalai (`shims/`) - ką jie keičia ir kodėl tai saugu

Visi jie liečia **aplinką, ne algoritmą**. Nė vienas nekeičia to, kaip
skaičiuojamos atramos.

| pakaitalas | kodėl |
|---|---|
| `oneapi/tbb/*`, `tbb/*` | Intel TBB = lygiagretumas. WASM naršyklėje sukasi viena gija, tad `parallel_for` virsta paprastu ciklu - lygiai tuo, ką daro paties libslic3r `ExecutionSeq`. Rezultatas tas pats, tik deterministiškesnis |
| `boost/log/*` | žurnalo rašymas. Tai kompiliuojama boost dalis, kurios Emscripten portas neturi; eilutės kode lieka, tik niekur nekeliauja |
| `boost/thread*` | tik užraktams - pakeista `std` atitikmenimis |
| `boost/beast/core.hpp` | libslic3r jį traukia TIK dėl base64; pilnas beast tempia `boost::asio`, kuriam Emscripten nėra nei Windows, nei POSIX |
| `LibBGCode/*`, `core/*` | binarinis G-code - FDM dalykas. Tipai tikri pagal formą, skaitymas visada grąžina klaidą, tad tas kelias niekada nepasileidžia |

## Patikrinta prieš etaloną (2026-08-19)

Tie patys keturi modeliai, tas pats profilis (`slicer-lab/prusa-full.ini`),
sluoksnis 0,05 mm:

| modelis | PrusaSlicer CLI | WASM | skirtumas | WASM laikas |
|---|---|---|---|---|
| puodelis | 2,4249 ml | 2,4081 ml | −0,7 % | 0,3 s |
| kronšteinas | 1,2209 ml | 1,2280 ml | +0,6 % | 0,05 s |
| evil (490k trikampių) | 16,2504 ml | 16,4300 ml | +1,1 % | 16,0 s |
| biustas (300k trikampių) | 18,3998 ml | 18,5751 ml | +1,0 % | 23,6 s |

Likutinis skirtumas paaiškinamas: PrusaSlicer dervą skaičiuoja iš rastrizuotų
sluoksnių (pikselių pustonai), `bridge.cpp` - tiesiai iš geometrijos.

Modulis: **3,0 MB**.

## Atramų tipas: `regular` ir `tree`

Tiltas priima trečią argumentą - kokio tipo atramas statyti:

```bash
node sla.js modelis.stl 0.05            # regular (numatytasis)
node sla.js modelis.stl 0.05 tree       # medžio (branching)
```

Tai ne tas pats algoritmas su kitu vardu: PrusaSlicer kiekvienam tipui turi
**atskirą parametrų rinkinį** (`support_*` ir `branchingsupport_*`), ir abu
paimti iš to paties profilio. Medžio variante galvutė plonesnė (0,4 vs 0,5 mm),
tiltas trumpesnis (5 vs 10 mm), stulpas platėjantis, jungimas dinaminis.

Puodelis, tas pats profilis:

| | PrusaSlicer | mūsų WASM |
|---|---|---|
| regular | 2,4249 ml | 2,4081 ml |
| tree | 2,2629 ml | 2,2995 ml |

**Ištirta (2026-08-19): tuščias padas su `tree` nėra klaida.**

`remove_redundant_parts` (Pad.cpp:307-316) palieka tik tas pado dalis, po
kuriomis yra atrama. Medžio atramos dažnai remiasi į patį modelį ir plokštės
nesiekia - tada pado po jomis ir nereikia.

| modelis | `regular` padas | `tree` padas |
|---|---|---|
| puodelis | 54,3 mm³ | 0 (atramos prasideda 1,44 mm) |
| biustas | 61,4 mm³ | 36,1 mm³ |

PrusaSlicer tam pačiam puodeliui elgiasi vienodai: su `tree` jo pirmi sluoksniai
15212 → 15400 → 15544 px (tik modelio kontūras), su `regular` - 37428 px.

## Ką reikia turėti galvoje

1. **CGAL apvalinimo tikrinimas išjungtas** (`-DCGAL_DISABLE_ROUNDING_MATH_CHECK`).
   WASM neturi apvalinimo režimo valdymo, o CGAL intervalų aritmetika juo
   remiasi. Keturiuose modeliuose rezultatas sutapo, bet tai neįrodo, kad taip
   bus visada - jei salų sėja kada nors duos keistą rezultatą, tikrinti pirma čia.
2. **Vienagijis.** Gijos naršyklėje reikalautų `SharedArrayBuffer` ir COOP/COEP
   antraščių, kurių gh-pages nustatyti negalima. Aukščiau esantis greitis - be jų.
3. **Licencija.** `libslic3r` yra AGPL-3.0-or-later, tad ir šis modulis yra
   išvestinis kūrinys su ta pačia licencija. `bridge.cpp` - taip pat. Likusi
   projekto dalis (firmware, pultas) lieka MIT ir yra atskirai.

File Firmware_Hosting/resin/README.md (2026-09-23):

# Resin profile library (gh-pages `/resin/`)

Source of the resin profiles the dashboard offers under **Settings → Resin →
Tested resin library** (0.17, plan item 0-16). Publish this folder to the
`gh-pages` branch as `/resin/`, next to `/bootanims/`.

## How it reaches the printer

The **browser** fetches `manifest.json` and then the profile file, and posts the
values to the printer's `/api/resin-profile/save`. The printer never fetches a
URL of its own, so there is no allowlist to maintain and no SSRF surface: a
profile is ~200 B of JSON, unlike a boot animation, which is why it does not
need the printer-side download path that `/bootanims/` uses.

## Preparing a profile

Do not hand-write these files. The private Resin Lab tool (its Library tab; not in
this repo) loads the published library,
fills a form from the real file, checks every value against the firmware's own
limits and writes `<slug>.json`, the whole `manifest.json` and `links.json` at
once, so they cannot drift apart. You type the real shop URL; the `/r/<slug>`
that goes into the profile is machinery and follows the name by itself. It publishes nothing by itself - the files are committed
here and to `gh-pages` by hand.

The page also owns the lifecycle a static folder has no room for:

- **Copy** - the same resin at the other layer height (0.05 / 0.10), which is the
  normal case rather than the exception.
- **Pause** - the entry leaves `profiles[]` for `hidden[]` (with a date, a reason
  and the row it stood in) while a complaint is being sorted out, and one click
  puts it back exactly where it was.
- **Retire** - same move, into `retired[]`, permanently.

`hidden` and `retired` live in the same `manifest.json`; the dashboard reads only
`.profiles`, so they are invisible to it.

⚠️ **A fix does not reach anyone who already installed the profile.** The library
list only offers profiles the printer does not have yet, and nothing re-checks it
afterwards. A correction that matters therefore ships under a **new slug** (the
page's *revision* button: `sunlu-tough` → `sunlu-tough-r2`), which is what makes
it show up again for everyone.

## Files

- `manifest.json` — what the dashboard lists. Per entry: `name` (slug, also the
  filename on the SD card), `display`, `file`, `layerHeight`, `testedBy`,
  `testedOn`, and optionally `buyUrl`.
- `<slug>.json` — the profile itself. Same keys the printer writes, so a profile
  saved on a printer can be published here unchanged.

## Two rules for adding a resin

1. **`tested_by` only for resin actually printed on a TinyMaker.** The badge
   names who tested it and travels inside the profile, so it stays visible after
   installation — that is what makes the recommendation worth anything.
2. **No manufacturer datasheet values.** This printer's colour TFT absorbs a lot
   of UV, so a "2-3 s" resin wants roughly 8-15 s here. Every number in a
   profile comes from the exposure test plus a weighing on the machine.

## `buyUrl` (affiliate, GitHub #55)

The firmware takes a buy link only from `https://tinymakerwifi.com/` or
`https://slibbinas.github.io/` (`resinBuyUrlAllowed()`), so a manufacturer URL
written straight into a profile was dropped on the way in: the link showed in
the library list and was gone from the installed profile. Every profile
therefore points at **`https://tinymakerwifi.com/r/<slug>`**, and where that
leads is `links.json` in this folder:

```json
{
  "sunlu-tough": "https://www.sunlu.com/",
  "anycubic-ww-clear": { "url": "https://www.anycubic.com/",
                         "geo": { "US": "https://www.anycubic.com/..." } }
}
```

A plain string is the normal case; the object form exists because the same resin
is bought in different places depending on where the buyer is. A slug missing
from the file shows no link at all - nothing breaks.

Resolved by the `/r/*` route in `Firmware_Hosting/feedback-worker` (302, edge-cached
5 min). Keeping the destination here rather than in the firmware is the point:
a partner changes with one commit, no firmware release, and the printer never
learns who the partner is.

⚠️ **An already-installed profile keeps the link it was installed with.** The
library only offers profiles the printer does not have yet, so the three
profiles installed before this shipped still carry no link. They pick it up by
being deleted and installed again - or, for a change that matters, under a new
slug (see the revision rule above).

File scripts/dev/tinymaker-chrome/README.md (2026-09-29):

# TinyMaker status - Chrome extension

Printer status on the Chrome toolbar. Reads `GET /api/status` once a minute (the
dashboard itself asks every 4 s) and never writes to the printer.

- **Icon badge:** `42%` while printing (orange), `II` paused, `SD` while the card is
  unpacking/deleting, `✓` after a print ends (until the popup is opened), `!` when the
  printer does not answer, nothing when idle.
- **Popup:** state, model, progress bar, **a preview of the printing model**, layer,
  running/remaining time with the end clock, resin used and left, SD, WiFi; **Open dashboard**
  (switches to an already open dashboard tab with the same address, or opens a new one); **Refresh**.
- **Notifications (0.3.0, opt-in):** turn them on in the options and a desktop note appears
  when a print finishes, the resin gets low, or the printer stops answering mid-print (each at
  most once per print). Off by default - the `notifications` permission is optional.
- **Printer address:** popup -> *Printer address* (default `tinymaker.local`; the IP works too).
  **Save** asks Chrome for access to that one address; a fresh install opens this page by
  itself and shows `?` on the icon until the address is saved. While the extension is not
  pinned to the toolbar, the options page says how to pin it (Chrome does not let an
  extension pin itself).

## Install

1. Copy this folder somewhere stable (e.g. `%USERPROFILE%\Tools\TinyMaker\tinymaker-chrome`).
2. `chrome://extensions` -> switch on **Developer mode** (top right).
3. **Load unpacked** -> pick the folder.
4. Puzzle icon on the toolbar -> pin **TinyMaker status**.

After changing the files: `chrome://extensions` -> the extension's reload arrow.

Since 0.2.0 the extension holds no site access when installed: `http://*/*` is only an
*optional* host permission, and the options page requests `http://<printer>/*` when the
address is saved (and drops the previous printer's access). The Chrome Web Store reviews
broad host access at length, and the extension only ever talks to the printer.

Package for the store: `python scripts/dev/pack_chrome_ext.py` (zip named after the
manifest version).

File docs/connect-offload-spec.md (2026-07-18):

# TinyMaker Connect offload — spec draft

Status: **draft for discussion** (V. Šidlauskas). Started 2026-07-13 after the
team-chat agreement; rewritten 2026-07-15 once measurements settled the
architecture. Audience: @Briadark (Connect server), @Tann2019.

Goal we already agree on: **Connect can grow as big as we like on the server
while the printer's flash footprint stays flat**, and Brian can ship Connect UI
without waiting for a firmware release.

---

## 1. Why this is worth doing

| | Today |
|---|---|
| Flash | 73.1% of 4 MB used. Every Connect screen competes with print features for the same bytes. |
| Iteration | A Connect UI tweak needs: firmware PR → review → release → every user OTAs. Brian's own product, gated on my calendar. |
| Transfers | Importing a model streams it **twice**: server → browser → printer. |

None of that is anybody's fault — Connect started inside the firmware because
that was the fastest way to prove it. It works. It just doesn't scale.

---

## 2. The constraint that decides the architecture

The obvious design — "Connect site talks to the printer's LAN API directly" —
**cannot work**, and it's worth stating plainly so nobody spends a weekend on it.

Measured 2026-07-15, Chrome 150:

```
page https://tinymakerwifi.com  →  fetch('http://192.168.1.138/api/status')
  ⇒ blocked: "Mixed Content: The page was loaded over HTTPS, but requested an
    insecure resource ... This request has been blocked."
```

The printer serves plain HTTP on the LAN and has no certificate, so **no HTTPS
page may call it from the browser** — CORS never even gets a say. This kills the
"printer as a REST API for the site" model regardless of how we configure it.
(It also means the CORS header currently sitting on `/api/boot-anim/install`
does nothing for an HTTPS caller — worth knowing before we rely on it.)

Two escape routes exist and both are worse: shipping a self-signed cert (browser
warnings on every visit) or leaning on Private Network Access (Chrome-only,
still moving). So we design around the constraint instead.

---

## 3. Proposed architecture: hosted UI in an iframe + a printer-side bridge

```
┌─ dashboard (http://tinymaker.local) ─ served by the printer ───────────┐
│                                                                        │
│  Connect tab                                                           │
│  ┌─ <iframe src="https://connect.tinymakerwifi.com/embed"> ─────────┐  │
│  │                                                                  │  │
│  │   Connect UI — 100% Brian's: models, previews, leaderboard,      │  │
│  │   boot-anim library, ratings, whatever comes next.               │  │
│  │   Ships when Brian deploys. No firmware release. No flash.       │  │
│  │                                                                  │  │
│  └──────────── postMessage bridge (versioned command set) ──────────┘  │
│                              │                                         │
│  dashboard JS = the gate: validates every command, then calls the      │
│  printer's own API same-origin (no mixed content, no CORS)             │
└────────────────────────────┬───────────────────────────────────────────┘
                             │  printer-pull for anything big
                             ▼
                  https://connect.tinymakerwifi.com/model/<id>.zip
```

**Why an iframe rather than today's `<script src=connect>` into our page.**
Today's hosted script runs *as* the dashboard: it can read the Connect token,
start prints, rewrite settings, anything. That's not a statement about trust —
it's that neither of us can audit or bound it, and it only gets harder as the
Connect UI grows. An iframe from a different origin can't touch the dashboard's
DOM or its APIs, so the blast radius becomes exactly the command list in §4.
It also ends the DOM coupling we're papering over today (`tidyConnectHosted()`
node-moves the hosted header; `.connectTabs` has to inherit our classes) — with
an iframe there is nothing to move and nothing to restyle.

**What each side owns**

| Printer firmware | Connect server |
|---|---|
| Connect settings + registration (secrets stay in NVS) | all model browsing, previews, ratings, "my models" management |
| The bridge and its command allowlist | leaderboard, boot-anim library, community pages |
| `/api/models/install`, `/api/boot-anim/install` (printer-pull) | serving `/embed` and the model/anim files |
| `/api/status`, `/api/files` (so the UI can say "already on SD") | look, layout, copy, iteration speed |
| Share-from-SD (only the printer can read layer PNGs) | |

---

## 4. The bridge contract

The iframe posts a message; the dashboard validates and answers. Nothing else
is reachable — no ad-hoc endpoint access, no token handout.

```js
// iframe → dashboard
{ v: 1, id: "<uuid>", cmd: "<name>", args: { ... } }
// dashboard → iframe
{ v: 1, id: "<uuid>", ok: true, data: { ... } }
{ v: 1, id: "<uuid>", ok: false, error: "printer busy" }
```

Both sides pin `event.origin` to the configured `connectBaseUrl` and drop
anything else. `v` is the contract version: the dashboard refuses a `v` it
doesn't implement, and the hosted UI can feature-detect via `hello`.

**v1 command set**

| cmd | args | does | gated by |
|---|---|---|---|
| `hello` | — | returns `{fw, build, v, caps[], printerName, connectId}` | — |
| `status` | — | the same object as `/api/status` | — |
| `files` | — | SD model list (so the UI can mark "on SD") | — |
| `model.install` | `{url, name, meta}` | **printer-pull**: the printer downloads and unpacks the ZIP itself | web control, idle, SD ready |
| `bootanim.install` | `{url, name, meta}` | same for a `.tmb` | web control, idle |
| `print.start` | `{name}` | starts a model already on SD | web control, idle, user confirm |
| `ui.resize` | `{height}` | iframe tells us how tall it is | — |
| `ui.theme` | — | dashboard pushes `light`/`dark` on load and on change | — |

Rules that don't change: **Web control off ⇒ every mutating command refuses**;
**printing ⇒ 409**; destructive things ask the user in *our* modal, not the
iframe's. `model.install` and `print.start` always confirm — the click came
from a page we don't control.

The publish token stays on the printer and is **never** handed to the iframe.
When the hosted UI needs to authenticate to its own server it uses its own
session (§6).

---

## 5. Printer-pull, and why `Import` and `Install` should become one thing

We already have two flows that mean the same thing to a user — "put this on my
printer" — built two different ways:

- **Boot animations** — `POST /api/boot-anim/install {url}` → the printer
  downloads the file itself. One stream, progress is real, browser is free.
- **Models (Connect Import)** — the browser downloads the ZIP, then uploads it
  to the printer. Two streams, the phone is the bottleneck, and the progress bar
  can only report the upload half (which is why it looked frozen at 100% while
  the ESP unpacked — fixed in 0.15.0, but the shape of the problem stays).

`model.install` collapses them: the printer pulls from `url` exactly like it
pulls a `.tmb`, and progress comes from the device that's actually working.
Roughly half the bytes over the air, and phones stop mattering.

There's a third win that only showed up while measuring. Today the unpack runs
*inside* the `/upload` handler, so the ESP can't answer `/api/status` until it
finishes — the browser cannot show the layer count that the printer's own
screen is displaying at that very moment. Answer `202` first and unpack from
`loop()`, and that number becomes readable over HTTP like any other status.

Brian, you called this "might hit two birds with one stone" when we discussed
the import indicator — this is that stone.

**Firmware side** (new, mirrors `handleApiBootAnimInstall`):
```
POST /api/models/install
  body: url=<https url>&name=<slug>&meta=<json>
  gates: web control, !busy, SD ready, url must start with connectBaseUrl
  behaviour: stream → temp folder → unpack → atomic swap (same as /upload)
  reply: 202 immediately; progress readable in /api/status
```
The `url` allowlist matters: without it the endpoint is a "make my printer
download anything" button.

---

## 6. Open question for Brian: where does the identity live?

"My shared models" management needs the publish token **on the site**, but the
token lives in printer NVS and, in the iframe model, the iframe never sees it.

- **(a) Server session** — the user claims their printer on the site with the
  recovery code, and from then on the site knows who they are without the
  printer. Clean, survives the printer being off, needs server work.
- **(b) Bridge-issued scoped token** — the dashboard asks the printer for a
  short-lived, read-only token and hands *that* to the iframe.
  No server work, but it's still a credential crossing a boundary.

I lean (a): it's the only one that still works when someone browses Connect from
the office. Your call — it's your server, and it decides the shape of the login
UI you'd have to build anyway.

---

## 7. Migration

| Step | Who | What |
|---|---|---|
| **0.15.0** (shipping) | done | Connect tab already slim: Models + boot-anim install; leaderboard is a link. |
| **1** | Brian | `/embed` route: the current Connect UI, no printer calls, bridge-ready. Ship whenever — nothing depends on firmware. |
| **2** | Viktoras | `POST /api/models/install` (printer-pull) + `model.install` in the bridge. |
| **3** | both | Dashboard swaps `<script>` for `<iframe>`; `tidyConnectHosted()` and the class-sharing hacks are deleted. Contract v1 frozen. |
| **4** | Brian | Model browsing/management move into `/embed`; firmware Connect tab shrinks to registration + the frame. |
| **5** | Viktoras | Delete the dead firmware paths; measure the flash we got back. |

Steps 1–2 are independent and can run in parallel. Nothing here needs a big-bang
release: the bridge can go in while the hosted UI still does everything the old
way.

---

## 8. What I'd like feedback on

1. Does `/embed` + bridge fit how you'd want to build Connect, or does it box you
   in somewhere I can't see?
2. The v1 command list — anything missing that you'd need in the next few months?
   Cheaper to add now than to version later.
3. Identity: (a) or (b) in §6?
4. Anything in §2 you've solved differently already — if HTTPS→LAN works for you
   somewhere, I'd want to know, because it would reopen the simpler design.

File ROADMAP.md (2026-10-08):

# TinyMakerWifi Roadmap

Where the WiFi / wireless-upload / OTA firmware for the open-source TinyMaker
MSLA resin printer is headed.

**The full, always-current roadmap - with the detail behind each line - lives at
[tinymakerwifi.com/roadmap](https://tinymakerwifi.com/roadmap/).** That page is the
single source and is refreshed at every release. This file is a short pointer, so
the repo never carries a second copy of the feature lists that drifts out of date.

## Where we are

| Version | State |
|---|---|
| **1.0.0** | current **stable** - what the automatic self-update installs. The 0.17-0.18 line promoted: the built-in browser slicer, live 3D progress, named resin profiles, power-loss resume, signed self-updates and drag-and-drop upload |
| **1.0.x** | fixes only - the features are frozen |
| **1.1** | next - new features; the list is on the [roadmap page](https://tinymakerwifi.com/roadmap/) |

New builds normally ship first as **betas** (from the [Releases page](https://github.com/slibbinas/TinyMakerWifi/releases)
and the dashboard's version picker); the automatic self-update stays on the previous
stable until the beta has proven itself, then it is promoted - so nobody is pushed
onto an untested build.

## Contributing

Small fixes, beta testing and bug reports are all first-class help. See
[CONTRIBUTING.md](CONTRIBUTING.md): small fixes → PRs to `main` (CI must be green),
ambitious work → PRs to `experimental`. Or just send a note through the
[feedback form](https://tinymakerwifi.com/feedback/) - 30 seconds, no account.

Version-by-version history: [CHANGELOG.md](CHANGELOG.md).

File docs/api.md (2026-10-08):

# TinyMakerWiFi LAN API (DRAFT v0 - 0-11)

> Status: **draft for review** - generated from the endpoint registrations in
> `src/Network.ino`; the contract rides `FIRMWARE_VERSION` (see Versioning policy
> below), so this doc is not pinned to a single release. Promised in
> [Issue #12](https://github.com/slibbinas/TinyMakerWifi/issues/12) as the
> versioned contract the Connect offload spec builds on.

## Transport & conventions

- Base URL: `http://tinymaker.local` (mDNS) or the printer's IP. Plain HTTP,
  LAN only - the printer never listens on the internet.
- JSON responses carry `"ok":true`; the dashboard treats a 200 **without** it
  as a truncated body. Errors answer `{"error":"..."}` with an HTTP code.
- **Busy gate**: while printing, every SD-touching endpoint answers
  `409 {"error":"printer busy"}` (the SD bus feeds the print). Status and
  print-control endpoints keep working.
- **Web control gate**: with *Web control* off (printer → System → Advanced →
  Network), state-changing endpoints answer `403`; viewing (status, files
  list, previews) keeps working. Slicer upload and MQTT are not gated.
- **Update gate**: web firmware flashing works while idle with Web control on,
  or whenever the printer sits on its Update screen (`otaWebAllowed()`); the
  dev espota path additionally requires the Update screen to be open.
- **CSRF gate (#95)**: on every endpoint behind the Web control gate, a
  non-GET request must also prove it comes from the printer's own page -
  either a browser `Origin` header matching `Host`, or the `X-TinyMaker: 1`
  header for scripts and tools (`curl -H "X-TinyMaker: 1" …`). A request with
  a foreign `Origin` is refused even with the header. GETs are open as before,
  and the ungated paths (PrusaSlicer upload, MQTT) stay ungated.

## Versioning policy

The contract rides the firmware's SemVer (`FIRMWARE_VERSION`). Additive
changes (new fields, new endpoints) bump minor and are safe to ignore.
Renames/removals are breaking and only land with a major bump, called out in
the changelog. Consumers (Connect bridge, dashboards) should ignore unknown
JSON fields.

## Discovery & status

| Endpoint | Method | Purpose |
|---|---|---|
| `/api/version` | GET | OctoPrint-compatible identity - lets PrusaSlicer's "Send to printer" test pass |
| `/api/status` | GET | The heartbeat: everything the dashboard shows, one poll |

Key `/api/status` fields (additive; ignore unknowns):

| Field | Meaning |
|---|---|
| `firmwareVersion`, `firmwareBuild`, `buildDate` | SemVer, git rev, compile moment |
| `dashEtag` | content hash of the dashboard page this firmware serves (0.17). The firmware version does not identify the page - a web-only change ships a new dashboard under an unchanged version - so a bug report needs both |
| `busy`, `paused`, `pausing`, `resuming`, `stopping` | print lifecycle booleans |
| `state`, `stateCode` | human text + numeric state |
| `canPause`, `canResume`, `canStop` | which controls are valid right now |
| `refillPending` | `true` while a low-resin pause (`stateCode` 10) is waiting for the VAT to be refilled. Resume is refused with `409 {"error":"only Stop available, please refill"}` until `POST /api/vat/refilled`, which marks a **full** refill (it sets the level to the VAT size; it does not measure what was poured). `/api/vat/weight` cannot be used here - it refuses a busy printer, a pause included. `canResume` stays `true` so clients can still show the paused controls (0.17) |
| `phaseTotalMs`, `phaseElapsedMs` | live phase countdown (0 = unknown) |
| `waitStage` | which *wait* the countdown belongs to, `""` for an ordinary layer phase (0.17). A stop or a pause is two waits, not one: `stopTail` (finishing the move that was in flight) then `stopLift` (the final platform lift), or `pauseWork` (finishing the layer) then `pauseLift`; plus `homingBack` (stop during homing) and `resume`. Clients that show a countdown should restart it when this value changes, and keep one message whose text follows the stage |
| `receiving`, `receivingName` | someone is uploading a model right now (0.17). While bytes arrive the printer mostly cannot answer at all, so a second device could not tell a transfer from a dead printer and flickered its "not answering" line on and off. `receiving` goes false ~5 s after the last chunk, which also covers a connection that died mid-transfer. It locks nothing - `busy` keeps its meaning, and the unpack that follows sets that itself |
| `layerHeight`, `dryRun` | active settings snapshot |
| `resinSet` | `false` when no resin profile is selected - `/api/print/start` refuses with 409 until one is picked, so a client should disable its Start controls. Lives here rather than in `/api/config` on purpose: this is polled, so a second open dashboard learns about a deleted profile within one poll (0-16) |
| `wifiRssi`, `wifiText`, `ip` | connectivity |
| `sdReady`, `sdText` | SD card state (`Locked` while printing) |
| `lifetimePrintSecs/Time`, `uvLedSecs/Time` | lifetime counters |
| `printsOk`, `thanksSeen` | how many prints ran to the end with the UV on, and whether the one-time thank-you note has already been shown on this printer (K8, 0.17.5). A dry run, an early Stop or a failed homing does not count |
| `bootReason`, `lastCrash{reason,layer,epoch}` | reset-reason telemetry (0-30); `lastCrash` null when none recorded |
| `model`, `currentLayer`, `totalLayers`, `layerText` | running print identity/progress |
| `previewCached` | the active model's preview PNG is held in RAM and fetchable mid-print (0-19) |
| `resinUsedMl`, `resinText`, `runSecs/Time`, `remainingSecs/Time` | consumption + timing |
| `vatRemainingMl`, `vatText`, `vatLow` | resin-in-VAT estimate + low flag |
| `vatGrams` | the same estimate in grams, using the configured resin density (R-cal, 0.17). `vatText` deliberately stays ml-only so older clients render unchanged |
| `webControl`, `askRefill` | runtime toggles |
| `sdJob`, `sdJobName`, `sdJobDone`, `sdJobTotal` | what the SD job is doing right now - `import` (unpacking an upload) or `delete` - the model it concerns, and how far it is (`0/0` = this job has no count). Lets every open dashboard show "Unpacking X 60/826" instead of the presser knowing and the observers guessing (1-32, SD-prog, 0.17) |
| `slicerOn` | the browser slicer module is switched on (SL-mod, 0.17). Also in `/api/config`; polled here so a second dashboard notices the switch within one poll |
| `liveN`, `liveCaptured` | the live 3D stack (P-live, 0.17): how many silhouette slots the running print has, and how many are captured so far - both `0` when idle. A client with no local slices fetches `/api/live/slices?since=<captured>` whenever `liveCaptured` grows |
| `resumePending` | `null`, or an object naming the interrupted `model` while the boot resume prompt is on the printer's screen (0-33) - the only window in which `/api/resume/*` is accepted |
| `sdRev` | SD content revision - bumps on any out-of-band SD change (upload/delete/boot-anim); a client reloads its file list when this changes (0-28) |
| `freeHeap`, `minFreeHeap`, `maxAllocHeap`, `uptimeSecs` | runtime diagnostics (heap + uptime) |

## Models & SD

| Endpoint | Method | Purpose / arguments |
|---|---|---|
| `/api/files/model/slices` | GET/POST | `name=<model>` - the packed 36-slice silhouette set the dashboard's 3D view needs, cached next to the model (~21 KB; re-fetching the 36 layer PNGs would take ~37 s). GET hands it back, POST stores what the browser computed. Idle-only, like every SD read |
| `/api/live/slices` | GET | `since=<k>` - the live 3D stack (P-live, 0.17): 1-bit silhouettes of the layers exposed so far, slots `[since, captured)`. RAM-only, so it answers **mid-print** - the one model endpoint that does; a full fetch also carries the not-yet-printed slots, which the browser draws as a ghost |
| `/api/files` | GET | SD inventory (models + archives) with sizes and free space |
| `/api/files/model` | GET | one model's details; `name=`, optional `estimate=1` for the resin estimate |
| `/api/files/model/metadata` | POST | update model metadata (`model.json`) |
| `/api/files/model/preview` | GET/POST | fetch / store the cached preview PNG; `name=`, `type=05|1`. While printing, the **active** model's preview is served from a RAM snapshot taken at print start (`type` ignored); other names, or a snapshot that did not fit in heap, answer `409` (0-19) |
| `/api/files/layer` | GET | a single layer PNG (browser-side slicing/preview). `source=1` (what the dashboard always sends) makes `i` the file number; without it `i` is a PRINT layer and 0.10 mm maps it to every other file |
| `/api/files/delete` | POST | delete an SD item; `name=` |
| `/upload` | POST | multipart model upload (`.sl1`/`.zip`); fields: `file`, `action=replace|rename` on a 409 name conflict, `source`, optional Connect credits fields |
| `/api/files/local` | POST | the same upload path with the OctoPrint shape - PrusaSlicer "Send to printer" |

Upload answers only after the on-printer unpack finishes (minutes for big
models); a name conflict returns `409` with a `conflict` body and the client
retries with `action`.

## Print control

| Endpoint | Method | Purpose |
|---|---|---|
| `/api/print/start` | POST | start a model (`name=`); a low-resin state answers `{"warning":"low_resin",...}` first - confirm and retry with `force=1`. Refuses with `409 {"error":"no resin selected - pick a resin before printing"}` when no resin profile is set (see `resinSet` below): without one the printer does not know which exposure to use |
| `/api/print/pause` / `resume` / `stop` | POST | lifecycle controls (guarded by `can*` flags). All three answer with `etaMs` (milliseconds left in the wait that was just started, 0 = unknown) and `stage` (the same vocabulary as `waitStage`), so a client can start counting before the next status poll. `etaMs` is a *remainder*, so pressing Stop twice does not rewind it |
| `/api/resume/accept` / `lift` / `discard` | POST | answer the boot power-loss prompt remotely; valid only while `/api/status` reports a non-null `resumePending` (any button press at the printer consumes the prompt and these answer 409). `accept` resumes the print, `lift` raises the plate off the stuck print (up only) and discards, `discard` just clears the checkpoint. All three queue the action for the printer's main loop and return `{"ok":true,"queued":true}` |
| `/api/vat/refilled` | POST | restart the resin estimate from a full VAT |
| `/api/thanks/seen` | POST | mark the one-time thank-you note as shown (K8, 0.17.5). Kept on the printer, so a second device does not ask again; nothing about a payment is sent or stored. Answers `{"thanksSeen":true,"first":true\|false}` - `first` is `false` if another client got there first. Web-control and busy guards apply |
| `/api/resin/calibrate` | POST | R-cal (0.17): teach the printer what a print really costs. `slot=1\|2&raw=<ml>&grams=<g>` writes ONE named sample (`clear=1` empties it); `grams=` alone records against the last finished print; `density=<g/ml>` alone stores a measured density and re-fits both samples; `reset=1` clears everything but the density. Idle-only (409 while printing), 400 when the numbers cannot match the estimate. Returns `{factor, fixedMl, twoPoint, ...}` |

### Resin calibration model (0.17)

The pixel estimate misses two independent things, so the firmware keeps two numbers:

```
used_ml = raw_geometric_ml * resinCalFactor + resinFixedMl
```

`resinCalFactor` scales with the model (pixel area, layer height, over-cure); `resinFixedMl`
is the per-print film left on the plate, which does not scale. A single weighed print cannot
separate a slope from an offset, so `/api/resin/calibrate` keeps up to two samples of clearly
different size and solves the line through them (`twoPoint:true`). With one sample only the
slope is fitted and the offset is left as it is.

`model.json` caches the **raw** geometric estimate, never the calibrated one - re-calibrating
therefore refreshes already-scanned models without re-decoding a single PNG.

`/api/config` exposes `resinCalFactor`, `resinFixedMl`, `resinDensity`, `lastPrintRawMl`
(-1 = no finished print yet), `calTwoPoint` (whether a real two-point fit is in force) and
`calSamples[] = [{slot, raw, grams, ml}]` - samples are stored in **grams** (what the scale
showed); `ml` is derived with the current density, so changing the density re-fits both.
Backups carry `calUnit:1` to mark the grams era; older files restore safely.

`/api/status` additionally reports `endstop` (the raw optical Z sensor reading) - added for
homing diagnostics.

It also reports where the plate is: `zSteps` (raw step counter), `zMm` (height above the
**home** position, not above the LCD - the physical zero is wherever the plate was
levelled) and `zKnown`. Treat `zSteps`/`zMm` as meaningless while `zKnown` is `false`:
the counter starts at 0 wherever the carriage happens to stand, so an unhomed printer
would otherwise claim "at home" for a plate parked up top. `zKnown` turns true only
when a homing run reaches the endstop, and false again the moment the next one starts;
a power-loss resume restores a checkpointed, deliberately down-biased count - an
estimate, not a measurement - and so leaves it false, as does a manual jog aimed above
the build height (nothing stops that move at the top, so the counter can outrun the
carriage). The value is only as fresh as the
poll that fetched it: during a print the printer can go seconds without answering.
Nothing here detects lost steps - the motor has no feedback.

## Settings, backup, restore

| Endpoint | Method | Purpose |
|---|---|---|
| `/api/config` | GET/POST | full settings read / form-encoded save |
| `/api/config/defaults` | POST | factory print/web settings, and with them the resin: the active profile returns to `slow`, its overlay is deleted from the card and the resin calibration is cleared. The printer's own "Back to Default" does the same and then reboots (the device flags only take effect at boot) |
| `/api/config/mqtt/defaults`, `/api/config/connect/defaults` | POST | reset one integration |
| `/api/config/backup` | GET | JSON backup download (includes secrets - handle with care) |
| `/api/config/backup/sd` | POST | write the backup to the SD card |
| `/api/config/restore`, `/api/config/restore/sd` | POST | restore from an uploaded JSON / from the SD copy |
| `/api/config/dry-run` | POST | `enabled=0|1` - the banner's quick toggle |

Dry run is a **mode, not a setting**: it is switched only by `/api/config/dry-run`.
A `POST /api/config` therefore leaves it alone unless the body actually carries a
`dry_run` field - unlike every other switch in that form, where a full post without
the field means “off”. Until 0.17 it followed the common rule, so every “Save config”
silently cleared dry run and the next print fired the UV LEDs (found 2026-09-01).
Values `0`, `false`, `off` and an empty value all mean off; anything else means on.

## Firmware update

| Endpoint | Method | Purpose |
|---|---|---|
| `/api/update` | GET | installed vs latest (printer-side check of the signed manifest on GitHub Pages), `hasUpdate`, `allowed` |
| `/api/update/install` | POST | self-update; no arg = latest, `version=X.Y.Z` = that release (strict SemVer validation, 400 on anything else) |
| `/update` | GET/POST | human fallback page / multipart `firmware.bin` flash |

Since 0.18 every self-update is authenticated by **our own signature**, not by
GitHub's TLS certificate. The printer fetches a signed manifest - `update.json`
for the latest stable, `firmware-X.Y.Z.json` for a picked version - holding the
version and the SHA-256 of that `firmware.bin`, verifies its ECDSA-P256 signature
against the public key compiled into the firmware (`src/update_pubkey.h`), and
activates the download only if the hash matches. It fails closed: a manifest
that does not verify means no update - the latest check then reports a failed
version check (`state` 4), and a picked version is refused on the printer's
screen (*Update refused - bad signature*).
The automatic channel is the stable one; betas are reachable only with
`version=X.Y.Z`. A file uploaded through `/update` is the owner's explicit choice
and is not signature-checked.

## Browser modules on the SD card

The dashboard needs two things it does not carry in flash: the 3D library and
the slicer. Both are fetched once from our GitHub Pages and then kept on the SD
card, so a printer with no internet still shows models and still slices. The
card is always tried first; a miss falls back to gh-pages, and a miss there
falls back to the plain canvas renderer (3D) or to no slicer at all.

| Endpoint | Method | Purpose |
|---|---|---|
| `/lib/three.js` | GET | the 3D library out of the card (stored gzipped, served with `Content-Encoding: gzip`); 404 when not cached |
| `/api/lib/three` | POST | store the gzipped library the browser just fetched. Verified against a SHA-256 **compiled into the firmware** - only our own published bytes are accepted |
| `/lib/<name>` | GET | one slicer file out of the card. Stored as `<name>.gz`, served under the plain name because the module resolves its satellites by relative name. `.wasm` is served as `application/wasm` |
| `/api/lib/slicer` | GET | which slicer version the card holds, read off the filenames: `{"version":"3.6.2","files":5}`. Needs no internet; 409 while printing |
| `/api/lib/slicer/check` | POST | `ver=X.Y.Z` - the printer fetches `lib/slicer-X.Y.Z.sha256` from gh-pages over **certificate-verified** HTTPS (`src/slicer_ca.h`), keeps the sums in RAM and answers with the file list and which of them are already on the card. Idle-only, and 503 until the clock is SNTP-synced (certificate dates need it) |
| `/api/lib/slicer` | POST | multipart upload of ONE file the check above authorised. The filename must be in the RAM list and the bytes must match its sum, or the file is deleted again |

**The manifest fetch is the one place in this firmware that validates a TLS
certificate.** Everywhere else (`version.txt`, self-update, pings) runs
`setInsecure()`. Here it matters more: what the manifest authorises is code the
dashboard later executes on its own origin, and the copy happens automatically
rather than on a button press. See `src/slicer_ca.h` for the anchors and for what
breaks if GitHub Pages ever changes issuer.

**Why the slicer verifies differently from three.js.** The three.js sum is a
constant in the firmware, which is fine for a library that moves once a year.
The slicer module is published far more often, and pinning it the same way
would mean a firmware release and a reflash for every version - so the printer
fetches the expected sums itself, over HTTPS, from the same host it already
trusts for self-update. Only ~400 bytes of manifest cross the internet from the
printer; the 3.6 MB payload travels browser to printer over the LAN. A LAN
device can still POST bytes, but they will not match a sum that came from our
host, so they never stay on the card.

Every write here is idle-only, needs Web control on, and needs the dashboard's
own `X-TinyMaker` header. `POST /api/lib/slicer/check` additionally refuses
while the slicer module is switched off (`slicer_on`).

The two **reads** - `GET /lib/<name>` and `GET /api/lib/slicer` - are open like
any other GET: they only hand back a file the printer wrote itself, after its
checksum matched. They are still idle-only, because the card belongs to the
print.

## Integrations

| Endpoint | Method | Purpose |
|---|---|---|
| `/api/telegram/test`, `/api/whatsapp/test`, `/api/discord/test` | POST | send a test notification with the saved credentials |
| `/api/connect/test`, `/register`, `/recovery-code`, `/backup` (GET/POST), `/restore` | POST/GET | TinyMaker Connect pairing + settings backup |
| `/api/boot-anim` (+ `/file`, `/select`, `/delete`, `/preview`, `/install`) | GET/POST | boot-animation management; `/install` pulls a `.tmb` only from allowlisted hosts (gh-pages library, configured Connect server) - other sources go onto the SD card by hand |
| `/api/resin-profile` | GET | resin profiles (0-16): the four built-in ones (`fast`, `fast-draft`, `slow`, `slow-fine` - two resins at both layer heights) plus `/resin/*.json` on the card, with `selected`. Works without an SD card - the built-ins live in flash |
| `/api/resin-profile/select` | POST | `name=<slug>` - copies the profile into the live settings (exposure, layers, all four lift settings, density, R-cal) and saves them |
| `/api/resin-profile/save` | POST | `name=<slug>&display=<label>[&mode=new]` - writes the CURRENT settings into that profile. With `base_exposure=…` and friends it writes those values instead, which is how the dashboard installs a library profile it fetched itself. `mode=new` refuses an existing name (409) |
| `/api/resin-profile/delete` | POST | `name=<slug>` - deletes the file; for a built-in this drops the overlay and restores the factory values |
| `/api/resin-profile/rename` | POST | `name=<slug>&to=<slug>[&display=<label>]` - SD-card profiles only (409 for a built-in). The name a human reads lives inside the file, so `display` is what actually changes on screen (up to 40 characters; longer is cut); without it the stored label is kept. `to` may equal `name` (a label-only change: the slug drops capitals and punctuation). The rewrite goes through a temporary file, so no failure can leave the card without a copy of the profile |
| `/api/vat/weight` | POST | `grams=<full vat on the scale>` - sets the remaining resin from a weighing, using the empty-vat weight (`vatEmptyG`) and the profile's density |

All four mutating resin routes are idle-only (`rejectIfBusy`) and also refuse
while a power-loss resume is pending (409): the second half of an interrupted
print has to come out with the same exposure as the first. **The same 409 guards every
other route that can move the layer height**: `/api/config`,
`/api/config/defaults`, `/api/config/restore`, `/api/config/restore/sd` and
`/api/connect/restore`. `POST /api/print/start` and `POST /api/files/delete` refuse
too: the plate is still in the vat with an unfinished object, and the record points at
that very model. That is because
the resume move is computed from the layer height in force when Resume is
pressed, and a changed height would drive the plate into the cured object. The
press itself re-checks, and refuses on the printer if the height no longer
matches the record.

`GET /api/resin-profile` lists each profile with `edited` (its numbers differ
from the built-in ones) and `overlay` (a file exists on the card). They are not
the same thing: an overlay holding the factory values is not an edit, but it is
still there to delete.

## Known consumers

Fields are only ever **added** to `/api/status`, never removed or renamed (see
[Versioning policy](#versioning-policy)). That promise is only as good as the list of
things known to depend on it, so consumers are recorded here.

### TinyStatus (Wear OS watch app)

[github.com/slibbinas/TinyStatus](https://github.com/slibbinas/TinyStatus) - read-only,
no writes. Confirmed against firmware 0.16.2 and 0.17.0.

From `/api/status`, 21 fields: `ok`, `busy`, `paused`, `stopping`, `stateCode`, `state`,
`waitStage`, `model`, `currentLayer`, `totalLayers`, `layerText`, `remainingSecs`,
`remainingTime`, `runSecs`, `runTime`, `resinUsedMl`, `resinText`, `vatRemainingMl`,
`vatText`, `vatLow`, `ip`.

From `/api/config`, 2 fields, read about once a day: `lowResinWarnMl`, `lowResinMl`.

### The dependency that is not a field name

**`busy` falling from `true` to `false` is what "the print finished" means.** There is no
explicit end-of-print event, so a client's whole state machine hangs off that one
transition. If the timing of `busy` ever changed - staying `true` for a few seconds after
the last layer, say - every consumer would break, and **not one field name would have
changed**. The versioning policy above covers names; this is behaviour, and it is the
stronger promise of the two.

Adding a real end-of-print event would delete that guessing layer on every client at once.
Worth doing before there are many of them.

Then, in order of how much they carry:

* **`ok` is an integrity marker.** A `200` that arrives without it is treated as a
  truncated response and thrown away, so `ok` is not decoration - dropping it would make
  every reply look broken.
* **`stateCode` 4 and 10, plus `waitStage` `stopTail`/`stopLift`, tell a cancelled print
  apart from a finished one.** `waitStage` is the precision, not the mechanism: without it
  a client still recognises a cancel from `stopping` and `stateCode`, but a cancel that
  slipped past state 4 between two polls gets reported as stopped rather than cancelled.
* **`lowResinWarnMl` is read to warn at the level the person actually picked.** Missing, a
  client falls back to 5 ml - which was the firmware default until 0.17, and is now one of
  a range.

Polling load, for sizing: every 5 s while the app is open; nothing while closed, unless
background watching is on, and then every 30 s to 10 min **only while a print runs**,
stopping on its own 20 minutes after the print ends.

## Static

`/` (gzip dashboard), `/manifest.json`, `/pwa-icon-192.png` (PWA bits).

---

## Response examples

### `GET /api/files` (idle only - 409 `printer busy` while printing or during an SD job)

```json
{
  "ok": true,
  "sdReady": true,
  "usageKnown": true,
  "totalBytes": "31902400512",
  "freeBytes": "29804923904",
  "usedBytes": "2097476608",
  "usagePct": 6,
  "hiddenCount": 0,
  "items": [
    { "name": "ScreamingEvil", "type": "model",   "printable": true,
      "sizeBytes": "0", "importSeq": 7, "connectPublicId": "pub_ab12cd34" },
    { "name": "Benchy.sl1",    "type": "archive", "printable": false,
      "sizeBytes": "12582912" }
  ]
}
```

Byte counts are JSON **strings** (they can exceed 32-bit). `type` is
`model` (unpacked folder) or `archive` (an `.sl1`/`.zip` still in the SD
root - OK on the printer imports it). Model folders report `sizeBytes`
`"0"` - walking every layer file made the list O(models × layers) slow;
archives keep their cheap single-file size. `connectPublicId` appears only
on models imported from TinyMaker Connect. At most 64 items are listed;
`hiddenCount` is everything skipped (unmanaged root entries + overflow).

`importSeq` (0.17) is the arrival order - a counter the printer bumps on every
import, which the dashboard sorts on so the newest model is on top. A counter
and not a date on purpose: a printer with no internet never syncs NTP, and the
SD card's own FAT timestamps are all 2000-01-01 (the firmware registers no
date-time callback), so any date-based order would silently collapse back to
A-Z for exactly the people who could not tell why. Absent on models imported
before 0.17 and on archives - sort those last. A wall-clock stamp is written
alongside it into `model.json` (`created_epoch`) when the clock is real, but it
is display material, never the sort key.

### `GET /api/update`

```json
{
  "ok": true,
  "installed": "1.0.0",
  "latest": "1.0.0",
  "state": 2,
  "hasUpdate": false,
  "allowed": true
}
```

May block a few seconds while the (5-minute-cached) GitHub Pages version
check runs; mid-print it returns the cached state immediately. `state` is
the check's progress/outcome code; `allowed` mirrors the web-flash gate
(idle + Web control on, or the printer's Update screen) - when it is
`false`, `POST /api/update/install` will answer 403.

### `GET /api/links` (optional owner links - advanced)

A quiet, off-by-default touch for whoever runs the printer: drop a small
`links.json` at the **root of the SD card** and its entries show up in the
dashboard header, after *Feedback* and before the `?`. No file -> `404` and the
header is byte-for-byte as shipped, so a normal user who has no such file sees no
change. Handy for a maintainer or manufacturer (e.g. a private crash-telemetry or
resin-library link on your own machine); the user manual describes it too.

Format - a JSON array of `{"t": label, "u": url}`, at most 8 entries,
`http`/`https` only, file <= 4 KB:

```json
[
  {"t": "TinyMaker3D", "u": "https://tinymaker3d.com/"},
  {"t": "Community (FB)", "u": "https://www.facebook.com/groups/1486879621729571"}
]
```

A ready sample lives at [links.example.json](links.example.json): copy it to the
SD card root, rename to `links.json`, edit the entries, reinsert the card and
reload the dashboard (F5). Idle-only (`409` while printing, like every SD read);
the firmware only streams the file, never writes it. The dashboard accepts only
`http`/`https` links and renders labels as text, so a bad entry is dropped rather
than trusted.

---

*TODO before 1.0.0: settle the deprecation-window wording with Brian.*

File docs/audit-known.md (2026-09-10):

# Known and accepted - do not report these again

Findings that have been looked at, understood and **deliberately left as they
are**. An audit that lists them again is repeating work, not finding anything:
say "known" and move on. Anything not on this list is fair game.

Each entry says why it stays. If the reason stops being true, the entry goes.

| Where | What | Why it stays |
|---|---|---|
| `src/Network.ino`, resin rename | The rewrite normalises the file: values are clamped to their allowed ranges, missing keys are materialised from the factory `slow` recipe, and fields the reader does not know are dropped. | Fixing it means editing JSON in place on an ESP32 to preserve bytes nobody reads. The effective values do not change - the reader would have clamped them anyway. Cost far above the benefit. |
| `src/ResinProfile.ino`, `RESIN_JSON_MAX` | A profile file of 1 KB or more cannot be renamed (the read fails, the endpoint answers 500). | Real profiles are ~430 B. Only a hand-written file could hit this, and raising the limit costs RAM on a board that has none to spare. |
| `web/parts/slicer.js`, `slicerScaleUI` | The scale field rounds **down** (2.75 % is shown and applied as 2.7 %), so the number in the box is not exactly the model's scale. | Deliberate: rounding to nearest let a mere tap on the control make the model bigger than it was, which pushed it back outside the build volume. Down is the safe direction. |
| `web/parts/slicer.js`, slice Stop | Stopping relies on the slicer module (loaded from gh-pages, not in this repo) not catching the exception thrown from our progress callback. | Cannot be verified from this repository. The module has no try/catch around those calls today, and there is a second guard after the slice returns. Worst case is cosmetic: the button stays "Stopping..." until the run ends and no result is issued. |
| `web/parts/slicer.js`, save flow | `namesBefore` is read from `filesItems`, which can be stale, so the rename path may fail to identify the new model and fall back to "pick it from the list". | Graceful degradation by design: opening the wrong model is the thing being avoided, and the fallback says exactly what to do. |
| `web/dashboard.html`, `repaintPreviewForTheme` | Two branches (`markPreviewStopped`, `dashPreviewPlaceholder`) are effectively unreachable, because both paint through `paintPreviewProgress` and are therefore caught by the remembered-message branch above them. | Dead code, identical behaviour either way. Removing it would mean re-testing six preview states for no user-visible gain. |

## Deferred, with a decision behind it

| Where | What | Decision |
|---|---|---|
| `src/ResinProfile.ino`, `resinBuyUrlAllowed` | Library profiles carry vendor "Buy" links (`sunlu.com`, `anycubic.com`), but the firmware only accepts links from `tinymakerwifi.com` and `slibbinas.github.io`, so those links are dropped on read and no Buy button appears. | **Not a bug to fix here.** It is the affiliate model's shape: the link should point at our own catalogue, which then forwards. V decided (08-17) to settle it when the release and its documentation are prepared, not before. |

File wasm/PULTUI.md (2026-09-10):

# Prašymas pulto sesijai: prijungti WASM slicerį

Slicerio pusė paruošta ir išbandyta. Kad ji pasiektų naudotoją, pulte
(`web/dashboard.html`) reikia keturių smulkių pakeitimų - jie **surašyti į
[`pultas.patch`](pultas.patch)** ir čia paaiškinti žmogiškai.

Slicerio šaka pulto failų neliečia (repo sargas to neleidžia, ir teisingai:
kitaip tie patys pakeitimai atsirastų dviejose vietose), todėl paliekama kaip
prašymas.

```bash
git apply wasm/pultas.patch      # printerio šakoje
```

## Kas keičiasi (4 vietos, 24 pridėtos eilutės)

| # | Kas | Kodėl |
|---|---|---|
| 1 | **Atramų tipo jungiklis** slicerio kortelėje: `Supports · regular · tree` | V prašymas. `regular` numatytasis |
| 2 | Modulio adresas: `slicer.js` 0.9.0 → **`slicer-wasm.js` 3.0.0** | naujas variklis |
| 3 | `slice()` gauna `supportType` ir failo vardą | be to jungiklis nieko nekeistų |
| 4 | Tipo perjungimas panaikina ankstesnį rezultatą | kitaip „Save" išsaugotų tai, ko ekrane nebėra |

Pulto kodo logika **nesikeičia**: adapteris (`slicer-wasm.js`) turi tą pačią
API, kaip senasis modulis - tie patys `parseSTL`, `autoOrient`, `place`,
`bounds`, `fitCheck`, `toSceneMesh`, `detailBudget`, o `slice()` grąžina tokį
patį objektą (`blob`, `files`, `layers`, `rawMl`, `supports`).

## Ką dar reikia padaryti prieš tai

Modulis turi gulėti gh-pages šalia esamų:

```
lib/slicer-wasm.js          adapteris
lib/slicer-wasm-worker.js   darbininkas
lib/slicer-core.js          bazė (jau yra)
lib/sla-web.js              WASM įkroviklis
lib/sla-web.wasm            pats variklis (3 MB)
```

⚠️ **3 MB** - tiek naršyklė parsisiųs pirmą kartą (paskui ims iš savo talpyklos).
Per mobilų ryšį tai jaučiama; verta paskelbti su ilgu `Cache-Control`.

## Kaip patikrinta

Stende (`python scripts/dev/build_lab.py`), tikras pultas su netikru printeriu:

| | |
|---|---|
| modulis pasikrovė | `3.0.0-wasm` |
| puodelis, `regular` | 1,6 s · 300 sluoksnių · ~2,4 ml |
| puodelis, `tree` | 1,6 s · 300 sluoksnių · ~2,3 ml |
| eigos juosta | 2 → 9 → 14 → 85 → 92 → 98, atgal nešoka |
| `.sl1` prieš PrusaSlicer | puodelis −1,4 %, biustas +0,29 % |
| įkeltas į printerį | priėmė, parodė 300 sluoksnių ir 2,4 ml |

Detaliau - atmintyje `slicer-wasm-libslic3r` ir [README.md](README.md).

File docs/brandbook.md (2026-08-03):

# TinyMakerWifi — Brand & Design System

Internal design reference for the TinyMakerWifi web surfaces (landing page, user
manual, dashboard, social cards). It **documents the tokens already in use** so new
pages stay visually consistent and avoid a generic "AI-sloppy" look.

- Source of truth for these tokens: `docs/landing/index.html` (`:root` / `[data-theme=light]`),
  `web/dashboard.html` (`:root`), `docs/og-card.src.html`.
- Scope: web/marketing/docs only. The on-device firmware UI (Arduino_GFX screens) is
  constrained hardware rendering and is not governed here.
- Status: internal (git). Publish as a public page later if useful. Not on the firmware
  version ladder — changing this file has **no effect on releases** and never ships in
  `firmware.bin`.

---

## 1. Brand color

| Role | Value | Notes |
|---|---|---|
| **Accent / brand orange** | `#e8720c` | Primary buttons, logo, step numbers, highlights |
| Accent hover | `#c95f06` | Darker orange on hover for primary buttons |
| Logo arc (blue) | `#4da3ff` | The "WiFi / rising" arc over the logo bars |

The orange is the single brand signal. Use it for the one primary action per view; do not
paint large areas with it.

## 2. Logo

An SVG mark: three stacked orange bars (opacity `1` / `.75` / `.5`, largest at the bottom)
with a blue arc (`#4da3ff`) rising over them — reads as a printer/stack plus a WiFi signal.
Wordmark: **TinyMaker** in brand orange, "Wifi" in white/light. Font is the system stack
(below). Keep the arc blue — it is the only cool accent and carries the "wireless" meaning.

## 3. Palette (dark default → light)

Dark is the default theme; light is applied via `[data-theme=light]`.

| Token | Dark | Light |
|---|---|---|
| Background | `#141416` | `#f2f2f4` |
| Card / surface | `#1d1d20` | `#ffffff` |
| Line / border | `#26262a` / `#2c2c31` | `#dfe1e5` / `#d9dbe0` |
| Text | `#eeeeee` | `#1f2124` |
| Muted text | `#aaaaaa` / `#8a8a92` | `#5f6570` / `#6a707a` |
| Link | `#84bcf8` | `#155fb0` |
| Secondary button | `#2e2e33` (hover `#3c3c42`) | `#e2e4e8` (hover `#d3d6db`) |

**Status colors:** success `#2fbf4f`, warning `#ffb15f`, danger `#7b2f2f`.

> **Known variance to reconcile:** the dashboard uses a slightly different dark background
> (`#1c1c1e`, card `#2a2a2e`) than the landing/manual/og-card (`#141416`, card `#1d1d20`).
> Prefer `#141416` as the canonical brand background; align the dashboard when convenient.

## 4. Typography

- **Family:** `-apple-system, "Segoe UI", Roboto, sans-serif` (system stack — no web fonts,
  keeps pages self-contained and fast).
- **Code / monospace:** `monospace`.
- Body line-height ~`1.55`. Weights: `600` for buttons/emphasis, `700` for step badges.

## 5. Components

- **Primary button:** accent background `#e8720c`, white text, weight `600`,
  `border-radius: 10px`, hover `#c95f06`.
- **Secondary button:** `--btnsec` background, standard text color, same radius.
- **Badges / inputs:** `border-radius` ~`6–9px`.
- **Pills / avatars / step circles:** `border-radius: 50%`.
- **Theme-color meta:** `#141416` (dark) / `#f2f2f4` (light) — keep in sync with the palette.

## 6. Theming rules

- Ship **both** themes. Dark is default (`color-scheme: dark`); light via
  `:root[data-theme=light]` / `[data-theme=light]`.
- Drive colors through CSS custom properties (`--bg`, `--card`, `--text`, `--accent`, …),
  never hard-coded hex in markup, so the theme toggle works everywhere.
- Keep pages **self-contained**: inline CSS, no external fonts/CDNs.

## 7. Voice & tone

- Plain, friendly, respectful. Explain the human benefit, not just the mechanism.
- Lead with "free and open source"; credit **TinyMaker3D** for the original firmware/hardware.
- Support ask stays light: "Buy me a coffee ☕" (PayPal), never pushy.

---

*Related: Front-End Design skill trial (issue #61). When building or restyling a web page,
read this first and reuse these tokens rather than inventing new ones.*

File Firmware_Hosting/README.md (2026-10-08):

# Firmware hosting for self-update (GitHub Pages)

The printer's **System → Update** screen can check for a newer firmware and
install it over WiFi with no computer ("Install"). The files live on **GitHub
Pages** (the `gh-pages` branch), served from one host with no redirects.

Since 0.18 the printer trusts **our signature, not GitHub's certificate**. It
fetches a signed manifest `{"version","sha256","sig"}`, verifies the ECDSA-P256
signature against the public key compiled into the firmware
(`src/update_pubkey.h`), and flashes `firmware.bin` only if its SHA-256 matches.
A manifest that does not verify means no update (fail closed). The URLs are set
in `src/Network.ino`:

```c
#define OTA_MANIFEST_URL "https://slibbinas.github.io/TinyMakerWifi/update.json"
#define OTA_VERSION_URL  "https://slibbinas.github.io/TinyMakerWifi/version.txt"  // only for the base directory
```

The private signing key lives outside the repo (`~/.tinymaker/fw_signing_key.pem`,
or `$TINYMAKER_SIGNING_KEY`); create it once with `scripts/dev/gen_fw_signing_key.py`.
`release.py` refuses to publish without it. **Losing it means no printer can
update itself again until each one is flashed by hand** - keep a backup.

## Files to publish on `gh-pages`

`release.py` writes all of them (list below). For orientation: `firmware.bin` is
the app-only image (OTA image, **not** `firmware-full.bin`), built at
`C:/PIO-build/TinyMakerWiFi/tinymaker/firmware.bin`.

## One-time setup

1. Create the `gh-pages` branch (can be an orphan branch with only these files).
2. In the repo: **Settings → Pages → Build and deployment → Source: Deploy from a
   branch → `gh-pages` / root**.
3. Confirm the files are live:
   - `https://slibbinas.github.io/TinyMakerWifi/version.txt`
   - `https://slibbinas.github.io/TinyMakerWifi/firmware.bin`

## Each release (automated)

Since 0.11.0 the whole flow is one script (run from the repo root, with
`FIRMWARE_VERSION` already bumped in **both** envs of `platformio.ini` and the
release commit in place):

```
%USERPROFILE%\.platformio\penv\Scripts\python.exe scripts\release.py --notes-file notes.md
```

It builds both envs, pushes `main` + the `vX.Y.Z` tag, publishes to `gh-pages`
(`firmware.bin`, `firmware-X.Y.Z.bin`, `version.txt`, `versions.txt`) and
creates the GitHub Release with `firmware.bin` + `firmware-full.bin` attached.
`--dry-run` stops after the build; the GitHub token comes from the git
credential helper automatically.

## Files on `gh-pages`

- `update.json` - the **signed manifest of the stable release**; this is what
  the self-update reads.
- `firmware-X.Y.Z.json` - the signed manifest of each release; the version
  picker verifies it before installing that version.
- `firmware.bin` - the stable build; `firmware-X.Y.Z.bin` - one copy per release.
- `version.txt` - two lines: stable version + firmware.bin URL (kept for the
  dashboard and older references; the self-update no longer reads it).
- `version-beta.txt` - the newest beta (follows stable when there is none).
- `versions.txt` - the picker's list: one `X.Y.Z` per line, newest first.
- `builds.json` - `firmware.elf` SHA-256 of every release -> its version, so a
  crash report's build fingerprint resolves to the exact release.

A **beta** (`release.py --beta`) publishes `firmware-X.Y.Z.bin/.json`, the picker
list and `version-beta.txt`, but leaves `update.json` / `version.txt` /
`firmware.bin` on the previous stable. `--promote` later copies that version's
already-signed manifest to `update.json`, so promotion needs no key and ships the
exact bytes that were signed.

### Slicer module (0.17 SL-mod)

The slicer has its own ladder next to the firmware one, because it is published
far more often and installing it reboots nothing:

- `slicer-version.txt` - the newest slicer module version, one line.
- `slicer-versions.txt` - the picker's manifest: one `X.Y.Z` per line, newest first.
- `lib/slicer-X.Y.Z.sha256` - one line per file, `<64 hex>  <name>`. This is what
  the printer fetches to decide which bytes it will accept onto its card.
- `lib/*.gz` - the five files of the set, **already gzipped**: `slicer-wasm-X.Y.Z.js.gz`,
  `slicer-core-X.Y.Z.js.gz`, `slicer-wasm-worker-X.Y.Z.js.gz`, `sla-web-X.Y.Z.js.gz`
  and `sla-web-X.Y.Z.wasm.gz` (~3.6 MB in total).

The `.gz` copies must be published by us, not produced in the browser: browser
compression is not byte-reproducible, so no checksum would ever match (learned
with three.js on 08-12). The sums in `slicer-X.Y.Z.sha256` are the sums of the
**gzipped** files, which is exactly what travels over the wire.
  The browser fetches it straight from GitHub Pages (CORS is open).

The version check compares `MAJOR.MINOR.PATCH`, so "Install" only lights up when
`version.txt` is strictly newer than the running firmware. The dashboard's
picker also allows downgrades (with a warning).

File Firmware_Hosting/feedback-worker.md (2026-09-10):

# Feedback collector — DEPLOYED

Feedback forma (`tinymakerwifi.com/feedback/`, šaltinis `docs/feedback/`)
POST'ina į **atskirą** worker'į:

- **Worker:** `tinymaker-feedback` → https://tinymaker-feedback.slibbinas.workers.dev
- **Šaltinis:** [feedback-worker/](feedback-worker/) šiame repo (`wrangler.jsonc` + `src/index.js`)
- **KV:** namespace `tinymaker-feedback` (binding `FEEDBACK`)
- **Deploy:** `cd Firmware_Hosting/feedback-worker && npx wrangler deploy`
  (wrangler OAuth — `npx wrangler login`)
- Įdiegta 2026-07-15 (versija a72a1317). `tinymaker-stats` worker'is NELIESTAS —
  feedback gyvena atskirai, kad stats/ping niekada nenukentėtų nuo formos.

## Puslapiai ir KV panel'ai (tas pats worker'is servina daugiau nei feedback)

Tas pats `tinymaker-feedback` worker'is servina ir statiškus puslapius iš KV
raktų (`panel:*`). HTML įkeliamas iš PC su `wrangler`, NE iš repo.

| Route | KV raktas | Prieiga | Įkėlimas |
|---|---|---|---|
| `/tests` | `panel:tests` | viešas | `wrangler kv key put panel:tests --path <failas.html>` |
| `/plan` | `panel:plan` | secret **`LIST_KEY`** per `?key=`; blogas → **404** (nematomas) | `wrangler kv key put panel:plan --path planas.html` |
| `/team` | `panel:team` | KV raktas **`key:team`** per `?key=` (NE LIST_KEY); blogas → **404** | `wrangler kv key put panel:team --path <failas.html>` |

Proxy į gh-pages (be KV): `/demo`, `/manual`, `/roadmap`.

### `/tests/state` — testų pulto žymos serveryje (2026-08-27)

Pultas lieka viešas ir be rakto veikia kaip anksčiau (žymos tik toje naršyklėje).
Su asmeniniu raktu nuorodoje (`/tests?k=...`) žymos keliauja į serverių, tad
telefonas prie printerio ir kompiuteris ant stalo rodo tą pačią būseną, o
naršyklės išvalymas nebenužudo testavimo sesijos.

| | |
|---|---|
| Raktas prieigai | KV `key:tests` (kaip `key:team`); blogas ar joks → **404** |
| Būsena | KV `tests:state`, vienas JSON: `{"T-19":{"v":"pass","n":"...","t":<ms>}}` |
| `GET /tests/state?k=` | grąžina būseną |
| `POST /tests/state?k=` | prisiunčia **pilnuą to įrenginio kopiją**, grąžina sulietą būseną |

**Susiliejimas pagal eilutės laiką, ne pagal atsiuntimo eilę.** Abu įrenginiai
siunčia pilnas kopijas, tad vakar paliktas atidarytas langas kitaip nutrintų
tai, kas ka tik pažymėta telefone. Taisyklė gyvena atskirai — `src/state.mjs`
`mergeState()` — ir yra **unit-testuota**:

```
cd Firmware_Hosting/feedback-worker
node --test test/state.test.mjs
```

⚠️ Windows'e `node --test test/` (katalogas) nesuveikia — `MODULE_NOT_FOUND`;
paduok patį failą, kaip aukščiau.

**SEO / AI-discovery route'ai** (inline turinys `src/index.js`, ne KV — apex neturi
CNAME, tad worker juos servina pats): `/robots.txt`, `/sitemap.xml`, `/llms.txt`.
Turinį keisti tiesiai `index.js` + `wrangler deploy`.

**Gating pastaba:** `LIST_KEY` = Worker secret (`wrangler secret put LIST_KEY`);
`key:team` = KV raktas (vienintelis toks — `wrangler kv key put key:team <secret>`).
Blogas/nesamas raktas šiuose route'uose grąžina 404 (nematomą), ne 403.

**Maintainer feedback route'ai** (visi po `LIST_KEY`): `/feedback/inbox`,
`/feedback/csv`, `/feedback/list`, `/feedback/img`, `POST /feedback/mark`,
`POST /feedback/del`. Vieši: `/feedback/status?t=<token>`, `/feedback/recent`.

**Scope:** tas pats worker'is hostina ir atskirą **eInkWeather** projektą
(`/orai` ← `panel:orai`, `/oi/<code>` ← `oi:<code>` PNG'ai) — ne TinyMaker, čia
nedokumentuojama.

Pilnas route'ų/KV šaltinis: `feedback-worker/src/index.js`.

## Skaitymas

- CF dashboard → Storage & databases → Workers KV → `tinymaker-feedback`
  (raktai `fb:<ISO data>:<id>`, rikiuojasi chronologiškai), arba
- `npx wrangler kv key list --namespace-id 4eb7904e55fc490e854f85f631e6c35e`
- **`https://tinymakerwifi.com/feedback/list?key=<LIST_KEY>`** — 100 naujausių
  atsiliepimų JSON su `photoUrls` nuorodomis į nuotraukas. `LIST_KEY` secret'as
  NUSTATYTAS 2026-07-15 (reikšmę žino vartotojas; CF secret'ų atgal neparodo —
  pamiršus paleisti `npx wrangler secret put LIST_KEY` iš naujo). Blogas/nesamas
  raktas grąžina paprastą tekstą, ne duomenis.
- Nuotraukos: `GET /feedback/img?key=<LIST_KEY>&k=img:...` (tas pats vartas).

## Turnstile — įjungimas (kai prireiks; kodas jau paruoštas)

Worker'is Turnstile tikrina TIK jei nustatyti abu raktai — kitaip praleidžia.
Įjungti be jokio kodo pakeitimo:

1. CF dashboard → **Turnstile** → Add widget: vardas `tinymaker-feedback`,
   domenas `tinymakerwifi.com`, režimas **Managed**.
2. Gausi **Site Key** (viešas) ir **Secret Key**.
3. Iš `Firmware_Hosting/feedback-worker`:
   ```
   npx.cmd wrangler secret put TURNSTILE_SITEKEY   → įklijuoji Site Key
   npx.cmd wrangler secret put TURNSTILE_SECRET    → įklijuoji Secret Key
   ```
4. Viskas. Widget'as įsiterpia į formą pats (`<!--turnstile-->` vietoje), o
   POST pradeda tikrinti token'ą. Išjungti — `wrangler secret delete`.

## Anti-spam

- **60 s vartai / IP** (burst) + **paros lubos: 5 / IP, 60 iš viso**
  (skaitikliai `day:<data>[:<ip>]`, TTL 48 h).
- Kodėl lubos: KV nemokamas planas nustoja rašyti ties ~1000/parą, o vienas
  įrašas kainuoja ~3 rašymus (+1 už nuotrauką). Be lubų vienas žmogus po
  įrašą per minutę biudžetą sudegintų per ~7 val., ir **tikri atsiliepimai
  imtų tyliai nebeįsirašyti**. Su lubomis blogiausias atvejis ~500 rašymų.
- Atmestos užklausos tik SKAITO — todėl daužymas kainuoja skaitymus
  (100k/parą), ne brangius rašymus.
- CORS užrakintas į `https://tinymakerwifi.com`; forma ir POST — tas pats
  origin'as, tad CORS praktiškai net nedalyvauja.
- Testuojant lubas atmintinai išvalyti `day:*` ir `gate:*` raktus — kitaip
  paliksi savo paties IP užrakintą parai.

## `POST /slicerbug` — defektų žymės iš pulto (0.17)

Pulte (su `?dev=1`) galima bakstelėti į modelį 3D peržiūroje ir pažymėti, kur
blogai; „Send" atsiunčia žymes su milimetrais, slicerio versija, pulto ETag ir
firmware build'u, plius 3D kadrą kaip nuotrauką.

**Kodėl atskiras kelias, o ne `/feedback`:** pultas servinamas iš printerio per
`http://tinymaker.local` (arba LAN IP), tad viešos formos CORS
(`tinymakerwifi.com`) jį atmestų, o Turnstile widget'o puslapyje, kuris gali
neturėti interneto, nėra iš kur gauti. Viešos formos apsaugos **nekeičiamos** —
tai kitos durys su savo spyna.

| | |
|---|---|
| CORS | `*` **tik šiam keliui** (`WIDE_CORS` konstanta) |
| Turnstile | nėra |
| Limitai | 60 s / IP (`sbgate:<ip>`) · 20 per parą (`sbday:<data>`) · plius bendros 60/parą lubos |
| Kūnas | multipart arba JSON: `message` (≤8000), `fw`, `build`, `ua`, viena `photo` (≤2 MB, `image/*`) |
| Įrašas | ta pati `fb:` dėžutė, `src:'slicer'`, `tag:'bug'` iš karto — inbox'e matosi su ⌖ ženkleliu, „kas naujo feedback'e" pagauna savaime |

Kritimas be tinklo lieka pulte: „Copy" (iškarpinė) ir „JSON" (atsisiuntimas).

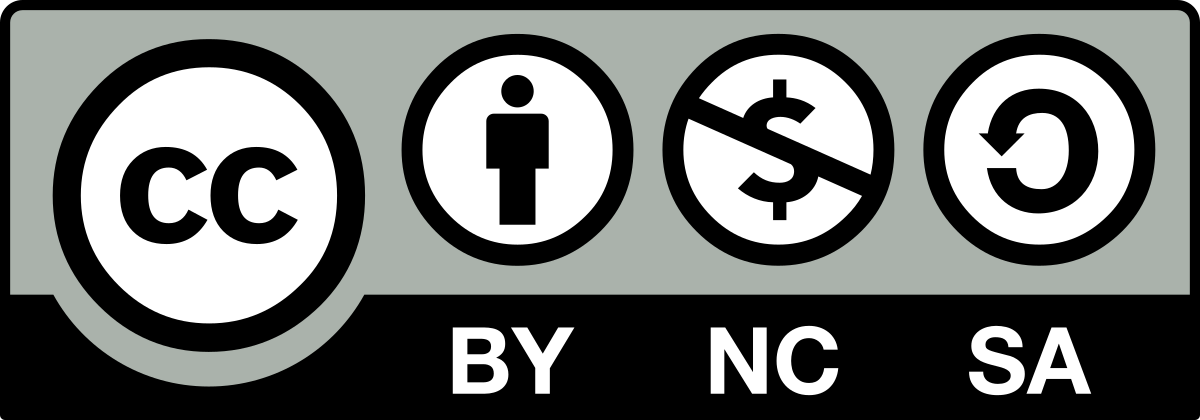
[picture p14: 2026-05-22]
Images/HARDWARE_LICENSE.png

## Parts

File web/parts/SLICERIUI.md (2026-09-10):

# Prašymas slicerio sesijai: WASM adapteris ir pulto vaizdas

Atsakymas į [`wasm/PULTUI.md`](https://github.com/slibbinas/TinyMakerWifi/blob/experimental2/wasm/PULTUI.md)
(šaka `experimental2`). Tęsia #107 - ten printerio pusė perdavė vartus, čia
grįžta viena kliūtis.

**Trumpai:** modulis veikia, bet perjungus pultą į jį ekrane po slicinimo
neliktų nieko - nei 3D vaizdo su atramomis, nei sluoksnių peržiūros, nei mėlynų
atramų ant sluoksnio. Failas išeina teisingas, „Save" veikia.

## Kas jau padaryta pulto pusėje

Keturios `pultas.patch` vietos perkeltos ranka į `0.17/slicer-merge`:
jungiklis `Supports · regular · tree`, modulio adresas, `slice()` argumentai,
perjungimas panaikina ankstesnį rezultatą.

⚠️ **`git apply` neveikia** - `experimental2` neturi `web/parts/`. Nuo 0.17
slicerio kortelė ir JS gyvena `web/parts/slicer-card.html` ir
`web/parts/slicer.js`, o pulte jų vietoje stovi `#include` žymės
(žr. CLAUDE.md „Pultas"). Kitą kartą pataisą verta rašyti prieš `parts/`.

## Kaip patikrinta (ne iš teksto - gyvai)

Įkeltas modulis iš gh-pages naršyklėje, supjaustytas 10 mm kubas:

| | |
|---|---|
| `slicer-wasm-3.0.0.js` | pasikrovė, `VERSION = 3.0.0-wasm` |
| kubas | 200 sluoksnių, 9 atramų taškai, 1,1 s |
| kito domeno riba | apeita, darbininkas pakyla |

## Ko trūksta (trys dalykai)

### 1. Trys vardai neperduoti toliau

Pultas kviečia `slicerMod.pillarDiscs`, `braceDiscs` ir `supportMesh`. Bazėje
(`slicer-core.js`) jie **yra**, adapteryje - ne. Užtenka įrašyti į tą patį
sąrašą:

```js
export const {
  parseSTL, autoOrient, place, bounds, fitCheck, toSceneMesh, detailBudget,
  zipStore, setFitMargin, PLATE, RES, LAYER_MM, SUP,
  pillarDiscs, braceDiscs, supportMesh,        // <- šito trūksta
} = BAZE;
```

### 2. Vaizdui nėra duomenų

`slice()` grąžina `preview: null`, o `supports.list` ir `braceList` - tuščius
(matau komentarą „WASM piešia pats - pultui piešti nereikia"). Pulte tai reiškia
du tuščius kelius:

- `slicerGeomView()` - 3D modelis + atramos; remiasi `supportMesh` ir `s.list`;
- `slicerBuildView()` - sluoksnių peržiūra; remiasi `slicerOut.preview`
  (`slices`, `gw`, `gh`, `modelH`).

Abu grįžta `false`, tad po slicinimo drobėje lieka tas pats vaizdas, kaip prieš.
Atramų atskyrimas spalva V pažymėtas kaip būtinas (08-13).

**Klausimas, ne reikalavimas:** kas jums pigiau -

- (a) grąžinti `preview` tokį patį, kaip senasis modulis, arba
- (b) pasakyti „vaizdą imkit per `geometrija()`" (STL dalys: modelis / atramos /
  padas). Tada pulto pusė prisijungia pati - tai mūsų darbas, tik reikia žinoti,
  kad taip ir turi būti, ir ar `geometrija()` galioja iškart po `slice()`.

Jei (b), pravartu ir tai, ar iš STL dalių įmanoma sluoksnių peržiūra, ar ji
lieka tik 3D.

### 3. Viduje adresai neprisegti

`slicer-wasm-3.0.0.js` yra bitas į bitą toks pat, kaip `slicer-wasm.js`, ir jo
viduje minimi neprisegti vardai: `slicer-core.js`, `slicer-wasm-worker.js`, o
darbininke - `sla-web.js` / `sla-web.wasm`.

Pulto taisyklė nuo 08-12: prisegamas **visas rinkinys**, nes sena naršyklės kešo
kopija po naujo adapterio yra tylus gedimas - tada V ieškojo pusdienį. Prašom
paskelbti `slicer-wasm-3.0.0.js`, kuris viduje rodo į `slicer-core-3.0.0.js`,
`slicer-wasm-worker-3.0.0.js` ir `sla-web-3.0.0.js/.wasm`.

## Smulkmena patikrinimui

Sintetinis kubas grąžino `rawMl: -1` (jūsų matuotas puodelis - 2,4 ml, tad
greičiausiai kalta mano rankinė STL be `autoOrient`/`place`). Verta žvilgtelėti,
ar `-1` negali ateiti ir per normalų kelią: pultas iš to skaičiaus rodo dervos
kiekį.

## Kol kas

Perjungimas **nesumergintas ir printeryje neįdiegtas** - pultas lieka ant
`slicer-2.0.2.js`, naudotojui niekas nesikeičia. Gavę 1 ir 2 punktus, užbaigiam
per vakarą kartu su firmware flash'u.

---

# 2 prašymas (08-19, po 3.0.1 prijungimo): modelis rastre guli kampe

3.0.1 prijungtas, kaukė ir `geometrija()` veikia - ačiū. Bet **`.sl1` rastras
išeina blogas**, ir tai matosi ne akimis, o išmatavus patį failą.

## Ką radom

Stende (tikras pultas, Ziedas.stl, 21,7 × 21,5 × 8,6 mm, `regular`) paėmėm
vidurinį sluoksnį - **ne mūsų piešinį, o patį PNG iš `slice()` grąžinto `files[]`**:

| | rasta | tikėtasi |
|---|---|---|
| rastras | 320 × 240 | 320 × 240 ✓ |
| objekto centras | **273, 194** | 160, 120 |
| ribos | 232…**319** × 157…**239** (remiasi į kraštą) | ~75…245 × ~35…205 |
| matomas plotis | ~88 px | ~170 px (7,84 px/mm) |

Kaukė (`supportSlices`) sutampa su PNG, tad pultas piešia teisingai - taip
atrodo pats variklio failas. Matomas **ketvirtis** objekto, nukirstas rastro
krašte.

## Kodėl taip, mūsų spėjimas

Skaičiai sutampa su viena prielaida: mes paduodam koordinates, kuriose **stalo
nulis yra centre** (modelis −10,8…+10,8 mm; taip grąžina `place()`, taip buvo ir
senajame modulyje), o variklis jas skaito taip, tarsi **nulis būtų stalo
kampas**. Tada į rastrą patenka tik teigiamas ketvirtis, o `display_mirror_x`
(ir y ašies kryptis) nuverčia jį į apatinį dešinį kampą:

    ketvirčio centras ≈ (7 mm, 7 mm) → (55, 55) px
    po veidrodžio       → (320−55, 240−55) = (265, 185) px     rasta: (273, 194)

Jūsų žinutėje buvo: „paduodant trikampiais variklis nieko nebecentruoja" -
panašu, kad būtent čia ir prasilenkėm: mes tikėjomės, kad koordinačių prasmė
lieka tokia pat, kaip senojo modulio.

## Ko prašom

Nuspręskit, kurioje pusėje kelti - abu variantai vienos eilutės:

- **(a) adapteryje**: prieš paduodant variklį, pridėti pusę stalo
  (`+PLATE.x/2, +PLATE.y/2`), t. y. adapteris ir toliau kalba ta pačia kalba,
  kaip senasis modulis. Mums tai patogiau: pultas paduoda `place()` rezultatą ir
  nieko nežino apie variklio vidų.
- **(b) pulte**: paduodam kampinėse koordinatėse. Padarysim, jei pasakysit, kad
  taip teisingiau - tik tada tai turi būti parašyta, nes `place()` grąžina
  centruotai ir tas pats masyvas eina į 3D vaizdą.

⚠️ Kol tai neišspręsta, **iš pulto slicinti negalima** - printeris gautų
ketvirtį modelio. Pas mus sliceris ant printerio įjungtas, tad tai skubu.

## Patikra, kai pataisysit

Mums užtenka vienos eilutės iš jūsų pusės, bet mes vis tiek pamatuosim tą patį:
vidurinio sluoksnio PNG objekto centras turi būti ~(160, 120), o plotis ~170 px
21,7 mm modeliui. Tada pultą perjungiam ir vedam per geležies vartus.

## Smulkmena, ne prašymas

`geometrija()` veikia puikiai - 3D vaizde atramos dabar tikros. Ačiū už tai, kad
dalys ateina `place()` koordinatėmis: tas kelias sutapo iš karto.

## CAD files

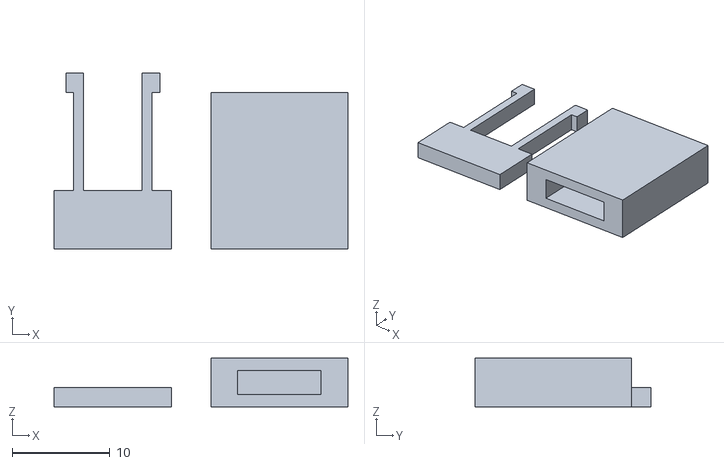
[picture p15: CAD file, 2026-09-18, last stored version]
scripts/dev/resin-lab/models/snap.stl
30.0 x 18.0 x 5.00

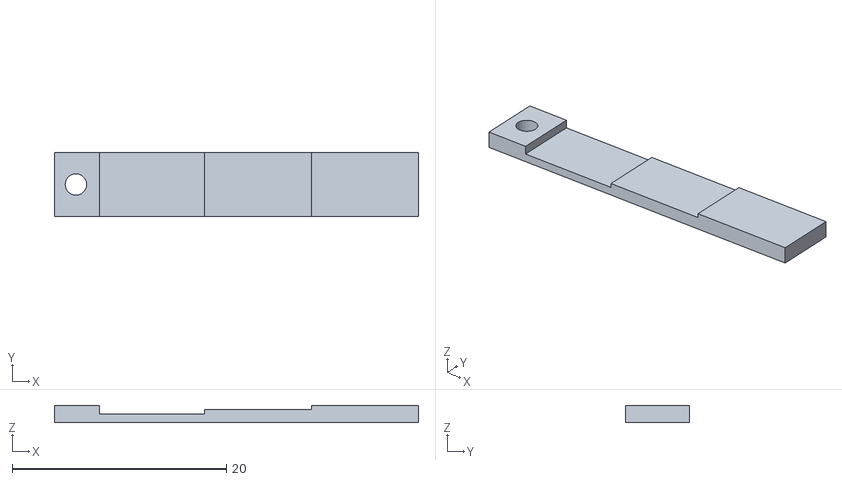
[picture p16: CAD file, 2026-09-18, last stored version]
scripts/dev/resin-lab/models/flexband.stl
34.0 x 6.00 x 1.60

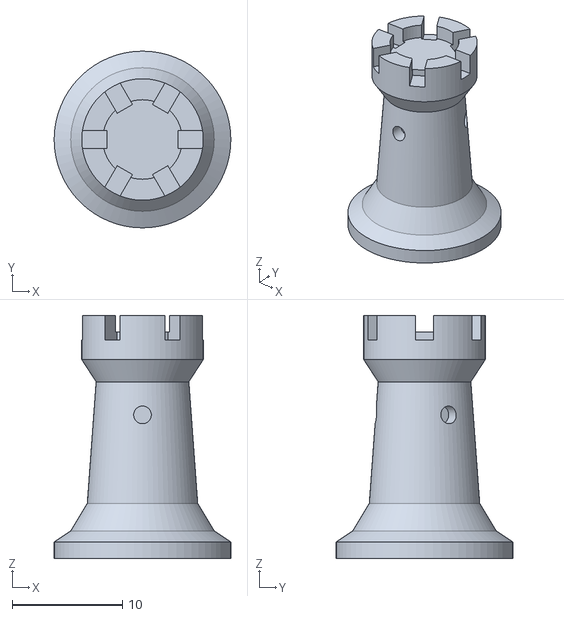
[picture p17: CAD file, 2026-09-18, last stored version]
scripts/dev/resin-lab/models/rook.stl
16.0 x 16.0 x 22.0

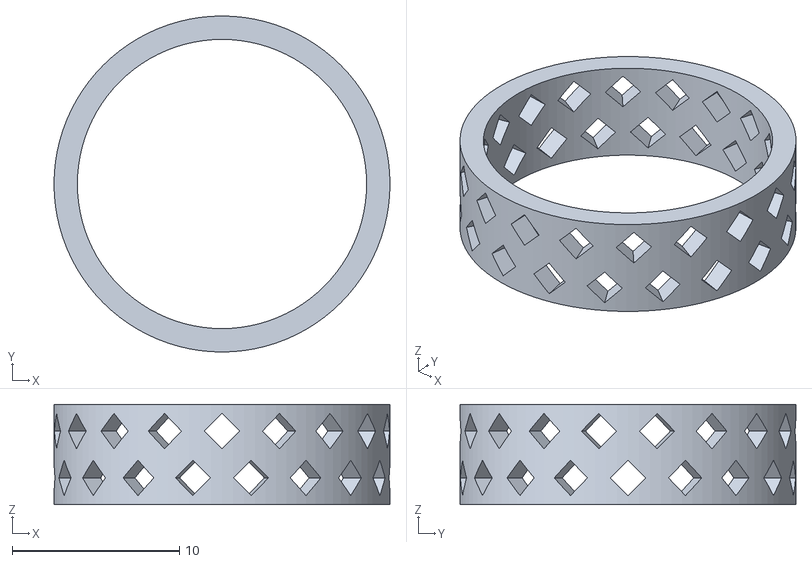
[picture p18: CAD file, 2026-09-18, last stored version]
scripts/dev/resin-lab/models/filigree.stl
20.1 x 20.1 x 6.00

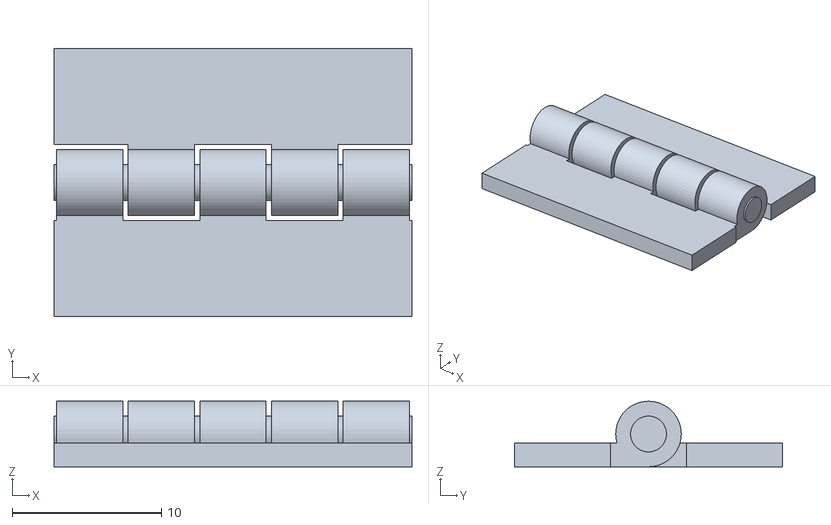
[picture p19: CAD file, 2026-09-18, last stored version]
scripts/dev/resin-lab/models/hinge.stl
24.0 x 18.0 x 4.40

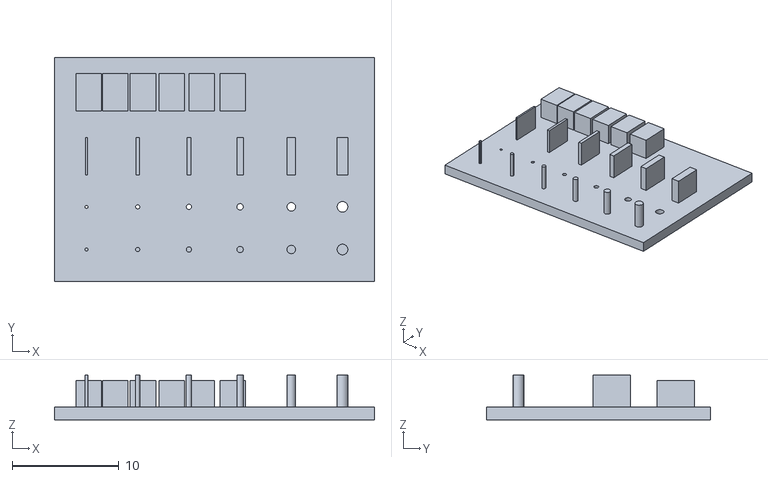
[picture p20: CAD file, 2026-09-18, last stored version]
scripts/dev/resin-lab/models/coupon.stl
30.0 x 21.0 x 4.20

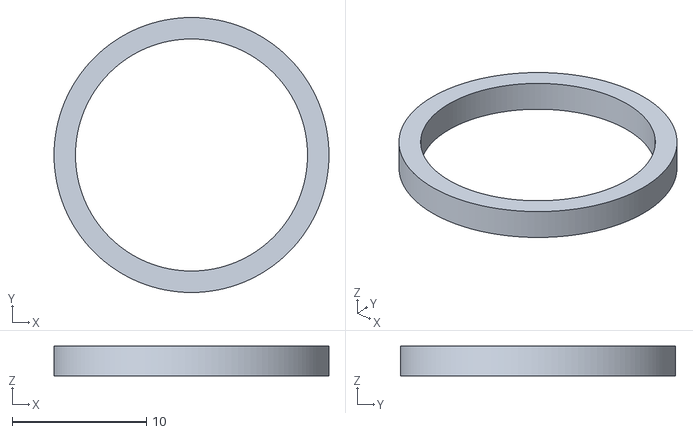
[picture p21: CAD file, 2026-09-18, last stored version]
scripts/dev/resin-lab/models/ring.stl
20.5 x 20.5 x 2.20

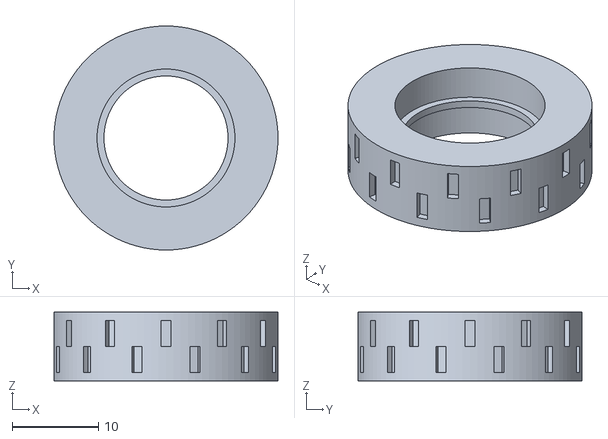
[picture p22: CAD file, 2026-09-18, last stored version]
scripts/dev/resin-lab/models/tire.stl
26.0 x 26.0 x 8.00

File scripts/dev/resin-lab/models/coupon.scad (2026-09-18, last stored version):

// Kalibracinis kuponas - bendras visiems dervų tipams.
// Spausdinamas tiesiai ant plokštės (be atramų). Eilės iš priekio į galą:
//   A smeigtukai, B skylutės, C plonos sienelės, D tarpai tarp blokelių.
// Skaičiai sąraše = matmuo mm, iš kairės į dešinę. Ekrano pikselis 0,1275 mm,
// tad 0,3 mm yra apie 2 pikselius - apatinė riba, kurią dar verta tikrinti.
$fn = 32;
L = 30; W = 21; T = 1.2;            // pagrindas
sizes = [0.3, 0.4, 0.5, 0.6, 0.8, 1.0];
walls = [0.2, 0.3, 0.4, 0.6, 0.8, 1.0];
gaps  = [0.1, 0.2, 0.3, 0.4, 0.5];
x0 = 3; dx = 4.8;

difference() {
  cube([L, W, T]);
  // B: skylutės per pagrindą (plokštė jas uždaro iš apačios - tikrinam, ar neužsipildo)
  for (i = [0:len(sizes)-1]) translate([x0 + i*dx, 7, -0.1]) cylinder(d = sizes[i], h = T + 0.2);
}
// A: smeigtukai 3 mm aukščio
for (i = [0:len(sizes)-1]) translate([x0 + i*dx, 3, T]) cylinder(d = sizes[i], h = 3);
// C: sienelės 3,5 mm ilgio, 3 mm aukščio
for (i = [0:len(walls)-1]) translate([x0 + i*dx - walls[i]/2, 10, T]) cube([walls[i], 3.5, 3]);
// D: blokeliai su vis platesniu tarpu
bx = 2.4;
for (i = [0:len(gaps)]) {
  xs = 2 + i*bx + (i > 0 ? sum(gaps, i) : 0);
  translate([xs, 16, T]) cube([bx, 3.5, 2.5]);
}
function sum(v, n) = n <= 0 ? 0 : v[n-1] + sum(v, n-1);

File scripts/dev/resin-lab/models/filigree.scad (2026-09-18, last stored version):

// Sudėtingas modelis lydomoms ir vaškinėms dervoms: ažūrinis žiedas.
// Plonos perėjos tarp skylučių (~0,5 mm) rodo, ar derva išlaiko smulkią
// juvelyrinę detalę. Spausdinamas gulsčias; vidinis skersmuo 17,3 mm (US 7).
$fn = 96;
ID = 17.3; th = 1.4; band = 6; n = 18;
difference() {
  cylinder(d = ID + 2*th, h = band);
  translate([0,0,-0.1]) cylinder(d = ID, h = band + 0.2);
  for (row = [0, 1]) for (i = [0:n-1])
    rotate([0, 0, i*360/n + row*180/n]) translate([ID/2 + th/2, 0, 1.6 + row*2.8])
      rotate([0, 90, 0]) rotate([0, 0, 45]) cube([1.5, 1.5, 4], center = true);
}

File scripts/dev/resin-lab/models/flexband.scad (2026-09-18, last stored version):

// Paprastas modelis lanksčioms dervoms: juostelė su trimis storiais.
// Lenkiama per pusę: turi grįžti į formą ir neįtrūkti. Storiausia dalis
// parodo, ar derva išlieka lanksti storesniame sluoksnyje.
th = [0.8, 1.2, 1.6];
seg = 10; w = 6;
for (i = [0:len(th)-1]) translate([i*seg, 0, 0]) cube([seg, w, th[i]]);
// ąselė galui sugriebti
translate([-4, 0, 0]) difference() { cube([4.2, w, 1.6]); translate([2, w/2, -0.1]) cylinder(d = 2, h = 2, $fn = 24); }

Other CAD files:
scripts/dev/resin-lab/models/hinge.scad
scripts/dev/resin-lab/models/ring.scad
scripts/dev/resin-lab/models/rook.scad
scripts/dev/resin-lab/models/snap.scad
scripts/dev/resin-lab/models/tire.scad
scripts/dev/resin-lab/models/tm_kaistukai.scad
scripts/dev/resin-lab/models/tm_spaustukas.scad
scripts/dev/resin-lab/models/tm_tiltai.scad

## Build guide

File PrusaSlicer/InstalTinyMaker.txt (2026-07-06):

Credits to https://www.reddit.com/r/3Dprinting/comments/1tqwl8c/tinymaker_slicer_profile/

Use UVtools, Help->Install profiles into PrusaSlicer, select the created TinyMaker printer profile, and check any 0.05mm print profile you want

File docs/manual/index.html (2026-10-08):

TinyMakerWifi (https://tinymakerwifi.com/) › Manual

User Manual · v1.0.1

# TinyMakerWifi

WiFi, wireless upload & over-the-air updates for the TinyMaker resin printer

by Viktoras Šidlauskas · @slibbinas (https://github.com/slibbinas) · tinymakerwifi.com

The palm-sized TinyMaker MSLA resin 3D printer

☰ Contents

## 1What this firmware adds

TinyMakerWifi is a modified firmware for the open-source TinyMaker (https://tinymaker3d.com/) MSLA (resin) 3D printer. It keeps everything the original firmware does and adds a wireless layer on top - so you can send models straight from your slicer and update the printer without ever touching the SD card or a USB cable.

- WiFi, set up from your phone on first boot - no credentials in code.
- Direct upload from PrusaSlicer with the “Send to printer” button.
- Import .sl1/.zip from the SD card - no network needed.
- A web dashboard - print status, controls, SD manager and a 3D preview in any browser, on the computer or on the phone.
- A slicer in the browser - drop in an STL and the dashboard slices it itself: orientation, supports, raft, a 3D and a layer-by-layer preview, then straight onto the SD card. No desktop slicer needed, and a phone is enough.
- Named resin profiles - the whole recipe for one resin (both exposures, base and transition layers, all four lifts, the density and its weighing calibration) under one name, switched in a single press. Four are built into the firmware - two resins at both layer heights; more can be installed from a published library.
- A real 3D preview, and live print progress - the model turns in the browser before you start, and while it prints the shape fills in layer by layer, on any device that opens the dashboard.
- Over-the-air firmware updates - the printer updates itself over WiFi.
- Resin estimation & level tracking - how much resin a model needs, and how much is left in the VAT.
- Home Assistant / MQTT integration (optional).
- Telegram, WhatsApp or Discord notifications - print finished / canceled / low-resin pause, straight to your phone.

Everything wireless can be switched off right on the printer (System → Advanced), so you can always fall back to plain, offline SD-card printing.

💡 Already have a printer running this firmware? Jump to Connecting to WiFi. If you are installing it for the first time, start at Installing the firmware.

## 2Quick start

1. Power on. On first boot the printer opens a TinyMaker-Setup WiFi hotspot.
2. Join it from your phone and pick your home WiFi in the little page that pops up. The printer reboots and connects (~5 s).
3. Find the printer’s address under System → WiFi Info (or use tinymaker.local).
4. Get a model onto the printer - three ways, pick one:
  - From PrusaSlicer - slice, then “Send to printer”.
  - From the dashboard - drop an STL into the browser slicer, let it slice, and it lands on the card ready to print.
  - By hand - copy an .sl1/.zip onto the SD card.
5. Print. Pick the model in the Print menu and press OK - or start it from the web dashboard.

## 3Installing the firmware (first time)

This one-time step is done over USB. After it, every future update is wireless (see Updating the firmware). If your printer already runs TinyMakerWifi, skip this section.

### Method 1 - the web flasher (recommended)

connect.tinymakerwifi.com/flash.php flashes the latest release straight from your browser - nothing to download or install:

🌐 Use Chrome or Edge. Web (USB) flashing needs the Web Serial API - Firefox and Safari don’t support it.

1. Connect the printer to your computer via USB.
2. Open the web flasher in Chrome or Edge (they support Web Serial; Firefox and Safari don’t).
3. Click Connect and pick the printer’s serial port. Unsure which one it is? Unplug and replug the USB cable and watch which entry appears.
4. Flash - the tool fetches the latest release by itself. Power-cycle the printer when it finishes.

🔌 Windows doesn’t see the printer? Install the CH340 USB driver (CH341SER.EXE, in the repo’s Driver folder), then try again.

### Flashing fails with “ERROR: Timeout”

If the flasher connects, downloads the firmware and then dies partway through Writing firmware-full.bin, the transfer speed is almost always the culprit - not the browser. Work down this list:

1. Lower the baud rate. The Baud rate dropdown on the flasher page defaults to 921600. Set it to 115200 and flash again. It takes a few minutes instead of about half a minute, but it copes far better with marginal cables and USB-serial chips.
2. Swap the USB cable. Charge-only cables, and cables with thin data lines, are the second most common cause. Use a short, known-good data cable.
3. Plug straight into the computer - not through a hub, dock, monitor or keyboard port.
4. Update the CH340 driver (see the note above) - an old Windows-bundled driver produces exactly this symptom.
5. Several ports in the picker? Unplug the printer, reopen the port picker, plug it back in, and choose the entry that appears.

💬 Still stuck after all five? Open an issue (https://github.com/slibbinas/TinyMakerWifi/issues) with the flasher log and the baud rate you used.

### Method 2 - already running TinyMakerWifi?

Then you don’t need USB at all: update over WiFi from System → Update on the printer, or from the dashboard’s Settings → Update - see Updating the firmware.

### Method 3 - manual flashing (fallback)

Download the latest firmware-full.bin from the project’s Releases page. Releases contain two files - they are not interchangeable:

File | Used for | How
firmware-full.bin | First-time USB flashing | flash at address 0x0
firmware.bin | Wireless updates only, later | browser, http://tinymaker.local/update

⚠️ For the USB flash you need firmware-full.bin. Flashing firmware.bin over USB leaves the printer unable to boot - it has no bootloader or partition table.

1. Open esptool.spacehuhn.com (a generic ESP flasher) in Chrome or Edge, plug in the printer via USB and click Connect.
2. Remove any pre-filled rows, click ADD, choose firmware-full.bin, and set its address to 0.
3. Click Program, wait for it to finish, then power-cycle the printer.

💡 The official Espressif Flash Download Tool is an alternative, and developers can flash a local build with esptool/PlatformIO - see the project README for the exact settings (SPI 40 MHz / DIO / 4 MB, file at 0x0).

The first boot after flashing takes a few extra seconds and starts the TinyMaker-Setup hotspot. Printer settings (exposure, layer height…) return to factory defaults - unless a settings backup is on the SD card: the printer then offers to restore everything on first boot (see Backup & restore).

## 4Connecting to WiFi

1. Power on the printer. On first boot it starts a TinyMaker-Setup access point.
2. Connect to it with your phone - a setup page opens automatically (or browse to http://192.168.4.1).
3. Choose your home WiFi network and enter the password.
4. The printer connects and briefly shows its IP address. Credentials are stored, so later boots connect on their own in about 5 seconds.

The TinyMaker-Setup captive portal as seen on a phone

On every later boot the printer shows animated signal bars while connecting - they turn green when it’s on the network, and the printer goes straight to the main menu (the IP address is only shown after the first-time portal setup). Need the address later? WiFi status, signal strength and IP are always under System → WiFi Info.

If the saved network can’t be reached, the printer simply boots offline after 15 s - printing from the SD card works as always.

### Resetting WiFi

To move the printer to another network, erase the stored credentials:

- From the menu: System → WiFi Info → press OK → confirm. The printer reboots into the TinyMaker-Setup portal.
- Emergency reset: hold the BACK button while powering the printer on - use this if it keeps trying an old network and you can’t reach the menu.

## 5The printer screens

The small status display drives the whole on-printer interface - WiFi setup, upload progress, the resin estimate, the device toggles and self-update. Three buttons: Back, Up and OK. A green (connected) or grey (offline) dot on the main menu shows WiFi status.

A montage of the TinyMakerWifi printer screens: boot, WiFi setup, printing, the Advanced groups, unpacking an upload, the Statistics counters, the plate notes at both ends of the travel and the resi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

The System menu is where the new features live: WiFi Info, Advanced (device toggles, grouped into Network / Resin / Display), Statistics (lifetime counters and the last boot/crash record), Update (firmware) and About (version and build info). The full item-by-item reference is in System menu reference.

## 6Printing from PrusaSlicer

The printer emulates the Prusa SL1 network protocol, so PrusaSlicer’s “Send to printer” works out of the box.

1. Download the TinyMaker printer profile (https://github.com/slibbinas/TinyMakerWifi/raw/main/PrusaSlicer/TinyMaker.ini) (TinyMaker.ini), then import it via File → Import → Import Config.
2. Save all three presets. Click the floppy-disk icon next to Print settings, Material and Printer and accept the names. Imported presets are temporary until saved - skip this and PrusaSlicer forgets the printer every time you close it, and you start over.
3. Add a physical printer: click the cog next to the printer profile → Add physical printer. Set Hostname to tinymaker.local (or the IP from System → WiFi Info); the API key can be any text.
4. Click Test - it should report success (the printer must be on and on WiFi).
5. Slice, then press Send to printer. The printer shows Receiving → Unpacking → Model ready, and the model appears in the Print menu.

PrusaSlicer: adding a physical printer pointing at tinymaker.local PrusaSlicer: the Send to printer button

⚠️ Always slice with the 0.05 mm profile. Maximum model size: 1200 layers = 60 mm.
Unlike an FDM slicer, the layer height here is set on the printer (Settings → Layer height), not in the file - the file is just a stack of 0.05 mm images, and at the 0.10 mm setting the firmware exposes every other one. Slice at anything else and the part comes out the wrong height: at 0.3 mm it would be six times too short.

♻️ Imported the profile a while ago? Import it again. The profile has changed since the early versions - the current one sets the screen the way the printer really uses it (display_orientation = landscape, 320×240 px over 40.8×30.6 mm). An old profile still slices and still uploads, but the layers come out turned, so the print is cropped at the edges and nothing on screen warns you.

💡 Layer height works differently than on an FDM printer. The printed layer height is decided by the printer’s own setting (Layer Height, in the printer’s Settings menu or the dashboard’s Settings tab) - not by the sliced file. The file is just a stack of 0.05 mm images: at the 0.05 mm setting the printer uses every image, at 0.10 mm it takes every other one. That’s why you always slice at 0.05 mm - the printer setting then chooses the real layer height, and a file sliced at 0.10 mm would print half-height.

## 7The built-in slicer (slice in the browser)

The firmware ships with its own SLA slicer, running right in the dashboard - no PrusaSlicer, no computer-side install, works from a phone too. Since 0.17.6 it is on from the start: the STL slicer card is already on the dashboard - press Open to unfold it. (If you would rather not have it, the switch is under Settings → Network → STL slicer in the dashboard.)

1. Choose STL and pick a model file - or drag the STL from your computer onto the slicer card. While you drag, a grey frame marks the card that will take it; on drop it flashes orange and the model loads (a folded card opens by itself), or red if the file is not an STL.
2. Stand it the right way up. Two switches under the slicer settings decide how the slicer places the part: Fit by - flat lays it on its widest side, supports searches for the rotation that needs the fewest supports, the way PrusaSlicer does, and tells you how much bigger or smaller the part can print than with a flat fit; and Size - keep leaves your size (scaling down only when the part itself does not fit; if only supports reach past the plate, the size stays and the card warns that the edge supports will be cut), max makes it as large as the plate allows, up to 300 %. Changing either switch re-places the part at once. Lay flat, Flip over, Tilt 90° and Rotate 90° are there when you would rather decide yourself, and the Fit button on the 3D view puts it back the way the two switches say.
3. Watch it slice - supports and a raft are generated automatically, and the dashboard locks under a spinner while it works, just like during a print.
4. Check the result in the preview: 3D with or without supports, the flat 2D layers, or the UV view - each layer exactly as the masking LCD will shine it.
5. Press Send to printer - the sliced model lands on the SD card ready to print, exactly like a PrusaSlicer upload.

Six settings sit under those buttons, and Reset to defaults puts them all back: Supports (no, regular or tree), Strength (light, normal, strong), Placement, Tip, Raft layers and Smoothing. You can slice without touching any of them - they only nudge what the slicer already decided.

Supports: no is for a part that is already flat or comes with its own supports from another program: nothing is added, the part is printed the way it sits in the file (only turned on the plate to fit), and the Strength, Placement and Tip settings lock. The raft is off by default; pick a raft size and it rings the base of the part. If the slicer module on the printer is older than 3.6.2, no stays locked until you update it under Settings > Update > Slicer module and reload the page.

💡 The raft is counted in layers, not millimetres, because layers are what decide whether the pad grips. Your file is always sliced at 0.05 mm and the printer decides how many of those images to expose, so the same setting is a different number of millimetres at a different layer height. The default is 3 layers; the choice is 2, 3 or 6. One layer is not offered any more - the pad does not bond to the part at all. Measured on this printer: a printed pad comes out about 0.15 mm thicker than asked, so 3 layers lands on the ~0.3 mm a PrusaSlicer plate gives, and lifts off with a spatula without force. And a thicker raft costs resin, not time: the pad thickens under the part, so the layer count stays where it was and only the resin grows. The exception is a part lifted off the plate - there the layers grow too.

A model sliced in the browser: the preview shows the part in orange standing on its raft with 180 support pillars in blue, and the slicer card reports the time, the layers, the resin and the support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

⚖️ The slicing itself is done by PrusaSlicer’s libslic3r, the same engine the desktop PrusaSlicer uses, compiled to run in your browser. It is used unmodified, under the AGPL-3.0 - see Credits.

The slicer itself is a module the printer keeps on its SD card: fetched once from our GitHub Pages, verified byte-for-byte against checksums the printer fetches over certificate-checked HTTPS, and served locally from then on. It survives firmware updates and works with no internet once cached. Its version is managed separately from the firmware - see the Slicer module card in Settings → Update; a slicer update never reflashes the printer.

💡 PrusaSlicer remains the fully-featured path - manual support placement, hollowing, fine-grained control over every parameter. The browser slicer is the zero-install path: an STL becomes a print in a couple of clicks, right where the printer already is.

## 8Printing from the SD card (no network)

No WiFi? Copy an .sl1 or .zip (exported by PrusaSlicer or UVtools) into the root of the SD card. It appears in the Print menu in blue, among the models.

- Press OK on a blue entry to convert it into a printable model (progress is shown). When done, the model appears in the list and the archive is deleted from the card.
- Long-press OK on a blue entry to delete the archive without importing.

## 9Starting & deleting models

In the Print menu:

- Start a print: select a model and give OK a short press. The preview shows Layers / Height / Time; press Up there to estimate resin (see below), or OK to start.
- Delete a model: press and hold OK for ~1.5 s. A Delete model? confirmation appears - release, then OK = delete, Back = keep. Large models take a moment (hundreds of layer files).

## 10Resin profiles, estimate & refills

The printer has no resin sensor - instead it keeps count. Every printed layer’s cured volume is subtracted from the VAT level, and the estimate survives reboots and firmware updates.

### Resin profiles

A profile is the whole print recipe for one resin: layer height, base and regular exposure, base and transition layers, all four lift settings, and the resin’s density with its weighing calibration. Switching resin is one press instead of ten fields, and a number that took an exposure test to find can no longer be lost to a stray edit.

Layer height is part of the profile, because exposure without it is only half a number: 0.05 mm needs less light than 0.10 mm. Two profiles for one resin is the normal case. What describes the printer rather than the resin - vat size, the low-resin levels, the pause lift - stays outside.

Four profiles are built into the firmware - two resins, each at both layer heights: Fast fine and Fast draft, Slow fine and Slow draft (fine is 0.05 mm, draft is 0.10 mm). So the list is never empty: no SD card, no network, and after a factory reset. The two Fast profiles ship with a weighing calibration measured on this printer (×1.010 + 0.63 ml); the Slow pair starts uncalibrated until you weigh a print. Editing a built-in writes a small overlay file on the card that shadows the flash values; Reset to factory deletes it. Every other profile lives in /resin/*.json on the card.

### Picking the resin

- Dashboard, main view: the resin row sits next to how much is left - which resin is in the vat is state, not a setting. Press it and pick from the list.
- Dashboard, Settings → Print: the same row, and the recipe opens underneath it.
- At the printer: System → Advanced → Resin → Resin profile steps through the installed profiles and applies the one shown. Creating and renaming stay in the dashboard - there is no keyboard at the machine.

With no profile selected the row reads “Not set - printing is blocked” and the printer refuses to start. That is deliberate: printing with nobody’s recipe used to run on whatever numbers happened to be left in memory.

The resin picker: the built-in profiles, installed ones, a profile marked tested by with a Buy link, the selected resin ticked, and a line offering ready-made profiles to install

### Installing a profile from the library

The picker also lists profiles you do not have yet, published by this project. Press Install and the profile is written to the card. A “✓ tested by” badge means someone actually printed with that resin on this printer and wrote down what worked - it saves you an exposure test. Some entries carry a Buy link. These are affiliate links: the shop pays this project a small share and the price stays the same for you - the picker says so right under the list.

Your browser fetches the profile and posts the values to the printer, so the printer itself never opens an outside address. Profiles you already have are not shown again - a corrected profile is therefore published under a new name, not silently swapped underneath you.

### Editing and saving

- Save stores the values in the printer and in the profile above it.
- Save as… keeps the original and starts a new profile from the values on screen.
- Rename… is offered for your own profiles (a built-in keeps its name).
- Discard changes appears as soon as a field differs from the saved profile and puts all ten back.
- Reset to factory appears when a built-in has been edited, and removes the overlay - together with the weighed prints stored in the same file; the confirmation says how many. Delete on a card profile takes its weighings the same way.

⚠️ A profile is a starting point. This printer’s colour screen absorbs UV, so manufacturer tables read far too short here - run the exposure test with your own resin and save the result.

Settings, Print tab: the selected profile with its whole recipe - layer height, exposures, layers and the four lift settings - then Save, Save as and Rename, the resin calibration by weight, and the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

### Grams instead of guesswork

Under Settings → Print → Resin calibration the printer learns to turn weight into millilitres for the resin above; the calibration travels inside the profile.

- Resin left, by weight: weigh the vat, type the grams, press Set. The printer subtracts the empty vat’s weight and divides by the density. The marker on the vat says full or not; a scale says how much, and that is the number the low-resin warning and the per-model estimate work with.
- Density is measured once per resin: weigh a known volume, enter both, press Set.
- Weighed prints: after a print, enter what the printer estimated and what the vat actually lost. Two such samples fit a correction curve - a multiplier plus a fixed amount per print, the film that stays on the plate - and from then on the estimate follows your resin rather than an assumption. On this printer the multiplier came out within 1 % of the geometry; the whole correction is about 0.6 ml of film per print.

### Estimate before printing

On a model’s print preview, press Up to estimate the resin it needs. It is shown in ml and in vat fills - e.g. 12.4 ml = 0.8 VAT. Your VAT size is adjustable (10–40 ml, default 15) in Settings. Live ml is shown while printing.

### Level tracking & refills

- “Resin left (est.)” is shown on the dashboard (and as a Home Assistant sensor with a low-resin alert).
- After a full refill, tell the printer: System → Advanced → Resin → Set VAT full, or the Set VAT full button on the dashboard - it works while printing too. The estimate restarts from a full VAT: it does not measure what you poured, so fill it to the top. Pouring less leaves the printer believing it has more resin than it does.
- Ask refill (default On): every print begins with a “VAT filled full?” question so the estimate stays honest - answer yes only after a full refill, because yes resets the level to a full VAT. Tidy users who press Set VAT full themselves can turn it off.
- Before a print, if the level is low (or a fresh estimate says the model needs more than what’s left), the printer shows “Low resin!” with the numbers - start anyway or go back.
- A heads-up before the stop (Warn (ml), 5–8 ml, default 5): while printing, the level crossing this mark says so on the screen and, if notifications are set up, on your phone - with the layer it is on, so you can decide whether to top up now or let it run.
- Low resin stop (default On): mid-print, when the level reaches Stop (ml) (3–8 ml, default 4), the printer finishes the layer, lifts and pauses with “Fill VAT full!”. Do a full refill, then press Set VAT full and resume - Resume stays locked until the refill is marked, and only Stop works meanwhile. On the printer itself, confirming “VAT filled full?” marks it and resumes.
- Why the stop cannot be set lower than 3 ml. The VAT is 42 × 52 mm inside, so one millimetre of resin is about 2.2 ml, and a full 15 ml VAT is under 7 mm deep. Poured resin stops covering the whole floor at about 4 ml, and it clings to the walls, so the middle can open a dry patch even a little above that. Below that level nothing prints, whatever the shape - so about 4 ml of every filling is there to be stood in, not printed with. On a 15 ml VAT that leaves roughly 11 ml to work with, which is worth knowing before starting a model the slicer says needs 20.

⚠️ It’s an estimate, not a measurement - it can’t account for resin sticking to models or drips. Treat it as a planning aid and glance at the real VAT now and then. For a real number instead of a running total, weigh the vat - see Grams instead of guesswork above. Refills you don’t confirm won’t be counted.

## 11The web dashboard

Open the printer’s IP address in any browser for the full dashboard: live print status and controls, SD-card management with one-click start/import, device settings and firmware updates - in tabs styled to match the printer. Three small icons at the top right pick the theme: System follows your phone or computer, Light and Dark stay put (your choice sticks per browser, and the Manual, Feedback and Roadmap links open in the same theme). Small ? marks next to the tricky settings open short explanations.

The Browser extension link next to Feedback leads to the TinyMaker browser extension (print progress on the toolbar, Chrome Web Store (https://chromewebstore.google.com/detail/tinymaker-status/bhfjpfjkhopfnfpapgahmaipdgmajlde)) and disappears once the extension is installed. A links.json file on the SD card adds your own links to that row - see the API notes (https://github.com/slibbinas/TinyMakerWifi/blob/main/docs/api.md) for the format.

🧪 No printer at hand? Try the dashboard live (https://tinymakerwifi.com/demo/) - the same UI driving a simulated printer: start a print, watch the 3D progress, poke through Settings.

💬 The Feedback link in the header opens a 30-second form - what works, what doesn't, what's missing. Photos are welcome (a failed print says more than a paragraph) and your firmware version comes along automatically. No account, and it genuinely steers what gets built next.

The dashboard in a narrow window: one column, with the status card, the print preview and the SD manager stacked

### While a print runs

The state line counts the current step down - Curing · 9s, Lifting · 4s - and after Stop or a finished print it counts the ride to the top the same way, so that wait finally has a number. Next to it a small dot says whether the printer answered just now (green) or is mid-move (amber, syncing).

The dashboard while printing: status with remaining time and finish-time estimate, print controls and the live 3D progress render

That dot is worth understanding, because it explains something that looks like a fault. One ESP32 runs the screen, the motor, the UV LED and this web server, all off a single SD card - so the page is served in the gaps between layer moves. During the peel the printer deliberately answers nothing: a pause there could mark the part. A few seconds of amber is the printer working, not the page hanging. How long the dashboard waits follows the print - the longest exposure plus 10 seconds. If your phone or laptop reaches the printer through a slow link such as a WiFi extender and the dashboard keeps saying the printer answers slowly, give it more time under Settings → Network → Wait while printing (kept in that browser only; 0 = automatic). The SD card is locked for the same reason: while a print runs, the slicer and SD cards fold down to their grey headers, and the SD card opens again when the print ends.

On a larger screen it spreads into two columns:

The TinyMakerWifi web dashboard on a wide screen: status and model preview on the left, STL slicer and SD manager on the right

New to the printer? A dismissible Getting Started checklist on the dashboard walks you through the first steps (WiFi → slicer → first model → first print → exposure calibration → integrations) - the printer ticks steps off by itself where it can.

Put it on your phone's home screen: open the dashboard in the phone browser and pick Add to Home screen (Chrome: the ⋮ menu; iPhone Safari: Share → Add to Home Screen). You get the printer's icon on the home screen, and on iPhone it opens fullscreen like an app. (A browser "install" banner won't appear - the printer serves plain HTTP on your LAN - but the shortcut works the same.)

### If the power drops mid-print

The printer writes a tiny checkpoint to the SD card as it goes, so a power cut is recoverable. When it boots back up it shows Power restored with the model name and the layer it reached, and three choices:

- Resume - the plate goes back down (no homing, which would drive the part into the vat) and the print continues from where it stopped.
- Lift plate (the up-arrow) - if you don't want to continue but the plate is pressed down on a stuck print, this clears the checkpoint first, then peels the part free and raises the plate.
- Discard - forget the interrupted print and boot normally.

Recovery is best-effort, not a perfect guarantee. If the outage happens during the exposure (the longest part of each layer, so the most likely moment), the plate's position is known exactly and the print continues cleanly. If it happens while the plate is mid-move (lifting or dropping between layers), the printer knows the plate's height from its last checkpoint during that move (see Resume mode below), so the resumed layers usually sit within a fraction of a millimetre - at worst a faint seam at that one spot. It never risks the opposite direction (into the FEP), so the worst case is a cosmetic mark or losing that print, never a damaged screen or film.

The same three buttons also appear on the dashboard the moment the printer comes back - so if the outage happened while you were away, you can resume (or lift, or discard) from your phone, as long as no one has touched the printer's buttons since it powered on. Before resuming, make sure the vat and the plate haven't been moved - the plate lowers back into the resin on trust.

Power the printer from its mains adapter, not a USB power bank. A weak or portable supply can sag the moment the plate lifts - the stepper's current draw briefly dips the voltage - and on a marginal supply that dip can even reset the printer part-way through the recovery. If a resume keeps rebooting back to the same prompt, that voltage dip is the usual cause: switch to the supplied adapter and try again.

Two settings decide how this behaves, both under System → Advanced → Resin (and in the dashboard’s Settings → Print). Power resume turns the whole thing on or off - off means the printer never checkpoints and always starts fresh, like the stock firmware. Resume mode chooses how finely it remembers: Balanced writes a checkpoint every 800 ms of plate movement, Precise every 400 ms - a resume closer to where the power went, at the cost of more writes to the card.

Power-loss checkpoint engine contributed by Tanner Steorts (https://github.com/Tann2019).

### The SD manager & the Model preview card

Uploads are safe: a model unpacks into a temporary folder and replaces the old one only after unpacking succeeds, and uploading a name that already exists asks Replace / Rename / Cancel (a PrusaSlicer re-upload simply replaces, as you’d expect while iterating).

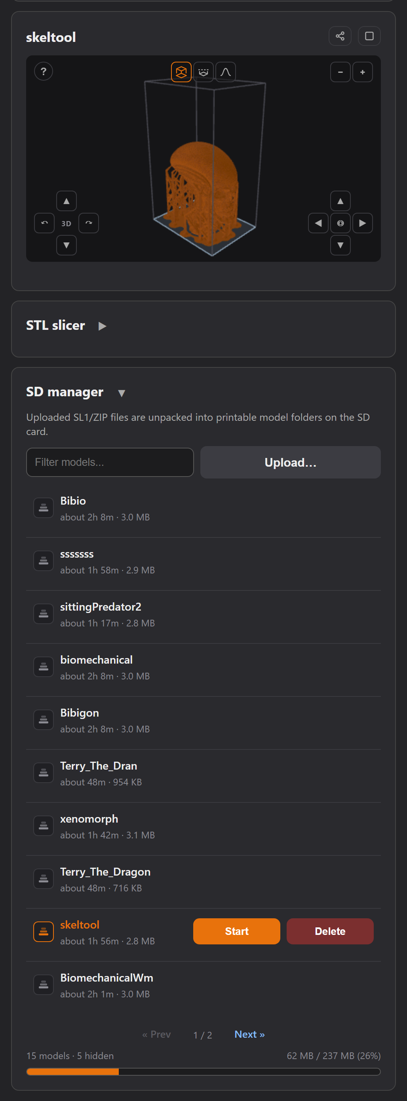
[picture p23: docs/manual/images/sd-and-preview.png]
The model preview card with a rendered model, its raft and its view controls, and below it the SD manager: a selected model with Start and Delete, the other models, the page arrows and the card-spac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


The card leads with the model list - the part you use every day. Upload… sits in its corner: one click opens the file picker and the file starts uploading the moment you choose it. You can also drag an .sl1 or .zip from your computer onto the card - the same grey frame while you drag, a short orange flash when the upload starts, red if the file does not belong here (an STL goes to the slicer card instead). Storage sits at the bottom as a thin bar, out of the way until it matters (it turns amber past 85%). Uploading a model that doesn't fit is refused before anything is sent, so the bar is information, not a thing to watch.

Every model row is the preview button: click it and the browser rebuilds the shape from the sliced layers and renders it into the Model preview card, with a live percentage while it loads, then a compact info line - layers · height · print time · resin - and a Share model button (when TinyMaker Connect is registered). The selected row is highlighted, so a card full of models never leaves you guessing which one is on screen. Start and Delete appear on the row itself - under the mouse on a computer, on a tap on the phone - and Start goes straight to the Start this print? question without waiting for the preview.

The card itself is always on the dashboard, like the SD manager: before anything is previewed it shows a hint, and the last previewed model is remembered - a page reload brings it straight back from the saved preview (no re-render, nothing to redo).

The preview is a real, smoothly-shaded 3D model rendered on the graphics card (three.js - fetched once, then kept on the printer's SD card, so it works with no internet and survives firmware updates). Around it:

- Rotate / zoom / pan with the mouse or fingers, an expand button for a bigger window, and a clip slider that cuts the model at any height so you can look inside - the cut shows the true voxel steps of the sliced layers.
- Two view buttons: the 3D one toggles supports on/off, the 2D one switches between the flat layer view and the UV view - the layer exactly as the masking LCD will shine it.
- Smooth rounds off the voxel steps for a prettier picture. It is off by default, because the same smoothing thins out anything flat and thin - the raft disappears altogether - and the preview's job is to show what will really be on the plate.
- Full print resolution, always - there is no quality switch to find. The first time a model is opened the browser decodes every layer (roughly a minute per model); the result is cached next to the model on the SD card, so from then on it is instant. Prepare 3D for all models (Settings → Display) runs that once for everything already on the card.

Resin on the info line: when the exact amount is known it is shown outright; otherwise a quick ~X ml (quick) estimate appears with the preview, free of charge. Clicking the ~ value runs the exact scan on the printer - it decodes every layer, so expect roughly a minute per 100 layers.

Start a print (from the row’s Start or on the printer) and the same card takes over automatically as a live progress render: the printed part fills in with color, the rest stays a ghost outline. It costs the printer nothing (the browser renders from a few prefetched layers).

The card’s title is a link. It names the model on screen, and clicking it takes the model list to the page that model sits on - useful once you have more models than fit on one page, and during a print, when the title reads Printing 42% · Tooth and you want that model in the list in front of you. Titles that name a state rather than a model - Model preview, Slicer preview - are plain text. The window itself is grown with the button in the card’s corner, and Esc brings it back.

Any device, at any point in the print. You do not have to have opened the preview beforehand, and it does not have to be the same browser or the same phone - open the dashboard an hour into a print, on a device that has never seen the model, and the growing shape is there. The printer keeps a small stack of layer silhouettes in memory as it prints and hands them to whoever asks, so nothing is read from the SD card mid-print. (Opening the preview first still gives the fuller picture: the complete model as a ghost, rather than only what has been printed so far.)

### Marking a defect

When the browser slicer is switched on, the preview grows one more control in its top-left corner: a defect marker. It exists for one job - telling us where something went wrong, instead of describing it in words a week later.

Press it and the view stops rotating: a red frame around the picture and a crosshair say you are marking, not looking. Drag a box over the bad spot - a support that grew into the part, a hole that closed, a raft that peeled - and add one line of text. A Defect markers panel appears under the preview card with every mark you made, each keeping the picture of that spot and the camera it was seen from, so the same view can be recreated later.

Four buttons finish the job: Send posts the report to the feedback inbox (the same one the dashboard header links to), while Copy and JSON keep it on your machine and Clear throws the marks away. Nothing leaves the printer until you press Send.

What travels with it, so nobody has to ask. The slicer version and where its module came from, the firmware version and build, the dashboard’s own checksum, the model’s name, layer count and scale, and for every mark the layer number written with its step (~L152 @0.10 mm) - because the preview counts in printer layers and the slicer in the ones it sliced, and the same spot is 152 in one and 302 in the other. Each mark also remembers whether it was made before slicing or on the sliced result, so one report can carry both “here is what I asked for” and “here is what came out”.

### The Settings tab

Settings is split into sections, switched by underline tabs - Print / Network / Notifications / Display / Backup / Update / About - shown one at a time, each with its own Save config button (saving from any section preserves the other sections’ values):

- Print - layer height, exposures, lifts, VAT size, resin profiles and the resin-tracking options.
- Network - the WiFi / Web control / boot-update-check switches, the Slicer switch, Wait while printing, the anonymous usage ping, MQTT, and TinyMaker Connect - including the Auto backup settings to Connect checkbox (it asks to confirm when toggled).
- Notifications - one choice of Telegram, WhatsApp or Discord (see notifications).
- Display - Boot animations and the 3D previews card with Prepare 3D for all models.
- Backup - just the actions: download / backup to SD / restore (see Backup & restore).
- Update - firmware install latest / version picker / Choose & flash…, and the Slicer module card (see Updating the firmware).
- About - versions, credits and links.

The Connect tab (shown once TinyMaker Connect is registered) is loaded from the Connect server and uses the same underline sub-tabs; its registration status is shown at the bottom.

## 12System menu reference

The System menu is where everything beyond printing lives. OK opens an item or changes a value, Back steps out:

System item | What it does
WiFi Info | Connected network, signal strength and the printer’s IP. OK here offers a WiFi reset (reboots into the setup portal).
Advanced | Device toggles, grouped into Network / Resin / Display - the tables below.
Statistics | Lifetime print hours, UV LED on-time, this boot’s reason and the last interrupted print (if any) with its layer.
Update | Installed vs latest firmware; installs a new version over WiFi. See Updating the firmware.
About | Firmware version, build date and the project link.

### Advanced → Network

Item | What it does
WiFi | On/Off - the whole network (web, PrusaSlicer upload, MQTT, self-update). Confirming reboots to apply; Cancel changes nothing.
Web control | On/Off - browser actions. Off = the dashboard turns view-only; slicer upload and MQTT keep working.
MQTT | On/Off (shown once MQTT is configured in the dashboard).
Boot update | On = the printer checks for new firmware right after WiFi connects at boot and offers Install / Later on the screen.

### Advanced → Resin

Item | What it does
Resin profile | Steps through the four built-in profiles and every profile on the card, applying the one shown. Reads “Not set - blocked” when none is chosen (printing is refused until one is), and a * after the name means that built-in has been edited. See Resin profiles.
Set VAT full | Press after a full refill - restarts the level estimate from a full VAT. It does not measure what you poured.
Low resin stop | On = mid-print, when the estimate reaches Stop (ml), the printer finishes the layer, lifts and pauses for a refill. On by default: below the stop level the VAT floor goes dry, and carrying on prints nothing.
Stop (ml) | The level that stops the print: 3 → 4 → 5 → 6 → 7 → 8 ml (OK cycles), default 4. Three is the measured floor of this VAT, not a preference - see how much is left.
Warn (ml) | The earlier heads-up, before the stop - on the screen and on your phone: 5 → 6 → 7 → 8 ml (OK cycles), default 5. Keep it above the stop level, or it has nothing left to warn about.
Ask refill | On = every print starts with a “VAT filled full?” question - yes resets the level to a full VAT.
Power resume | On = the printer checkpoints as it prints and offers to resume after a power cut. Off = it never checkpoints and always starts fresh, like the stock firmware.
Resume mode | Balanced writes a checkpoint every 800 ms of plate movement, Precise every 400 ms: a resume closer to where the power went, at the cost of more writes to the card.
Pause lift | How high the plate rises when you pause to look at the print: 20–40 mm in 5 mm steps (OK cycles). A dry run uses the same height instead of going to the top.
Exposure test | Cures an 8-bar calibration strip straight from the printer - each bar gets a different exposure time around your Regular setting. Pick the crispest bar and set its time in Settings. Resin in the vat, no build plate.
Dry run | Test prints without UV - motion and display only. Great for checking mechanics or a new model without wasting resin. Note: while Dry run is on, the UV LED stays off everywhere, including the exposure test.

### Advanced → Display

Item | What it does
Idle timeout | After this much inactivity the idle screen dims into a screen saver (“TinyMaker” + IP drifting around). 30 s…10 min, Off = never; fresh installs default to 60 s.
Boot animation | Which animation plays at power-on - OK cycles Default, Shuffle (with two or more installed) and every animation on the SD card (see Boot animations below).

- WiFi Off makes the printer fully offline, like the original firmware. Toggling it asks “Reboot now?”. Turn it back on right here - no reflash or reset needed.
- Web control Off makes the dashboard view-only: people can watch the print, but every action is disabled. Turn it back on on the printer (the settings form is one of the things it locks).
- If WiFi is off and you open System → Update, the printer offers to enable WiFi temporarily just for the update.

Both switches default to On and stay On after upgrading from an older version - nothing changes until you change it.

### Exposure calibration test

Exposure time is the single most important resin parameter - and every resin (even every color) cures differently. The test finds your resin’s time in one go: the printer cures an 8-bar strip straight from its masking LCD, each bar with a different exposure. No slicer, no SD file.

The bar times are proportional to your current Regular exposure (R) - from 40 % to 160 % of it, so the spread is meaningful for fast and slow resins alike. Bar 5 (100 %) is always your current setting:

Bar (dots) | 1 | 2 | 3 | 4 | 5 | 6 | 7 | 8
% of R | 40 | 55 | 70 | 85 | 100 | 115 | 135 | 160
R = 14 s | 6 | 8 | 10 | 12 | 14 | 16 | 19 | 22

⚙️ Regular exposure moves in tenths of a second (0.1 s steps, 1–30 s) - on the printer each press changes it by 0.1 s, and in the dashboard you can type the value straight in. Base exposure stays in whole seconds (5–60 s): it is about the first layers gripping the plate, where a tenth of a second changes nothing. Use the tenths for fine-tuning once the test has put you in the right area - not for finding that area in the first place.

The ladder follows your setting automatically. To test shorter (or longer) times, just change Regular exposure in one place - dashboard → Settings → Regular exposure → Save, or the printer’s Settings menu - and the test range recalculates itself; the Advanced menu row shows the current range (e.g. “2-16s strip”). After the test, set the winning bar’s time as your final value.

💡 Count the dots, not the sides. Each bar carries its number as holes near one end - 1 dot = bar 1 (shortest) … 8 dots = bar 8 (longest). The strip stays identifiable no matter how it is flipped or mirrored (the vat view often is!), and the dots double as a fine-detail check: on a well-exposed bar the holes come out round and open.

1. Prepare: resin in the vat (stir it first!), build plate removed - the strip cures directly on the vat film. Make sure Dry run is off.
2. Run: System → Advanced → Resin → Exposure test → Start. A progress bar runs for the longest bar’s time (~half a minute); Back cancels.
3. Peel & rinse: gloves on, lift the strip off the film with a soft plastic scraper, rinse in IPA, dry.
4. Judge the bars against the light:
  - Under-exposed (short end): thin, rubbery, fuzzy edges, breaks or partly stuck to the film.
  - Just right: sturdy, sharp clean edges, even thickness.
  - Over-exposed (long end): fatter than its neighbours, bloated edges, a thin parasitic film around it (light bleed).
  - All bars nearly identical? Your resin cures faster than the shortest step - lower Regular exposure (e.g. to 8 s) and run the test again. Note: a fresh, unwashed strip always feels rubbery; judge after an IPA rinse, and flexible resins (ABS-like) stay bendy by design.
5. Set it: pick the lowest time that still cures sharp and sturdy (best detail; if torn between two, take the longer one) and enter it as Regular exposure in Settings. Identify bars by their dots (1 dot = shortest) and read the time from the table above. Keep Base exposure at roughly 2.5× the new Regular - it’s about first-layer adhesion, not detail.

A real exposure test strip cured in the vat: eight bars with dot markers, holes crisp on the long-exposure side and sealing over toward the short side

A real test strip in the vat - count the dots: bar N carries N holes, so flipping or mirroring never confuses it. On the long-exposure side the holes cured round and open; toward the short side the bars turn translucent and the holes seal over. Pick the lowest bar whose holes are still open and edges sharp.

💡 Cold resin cures slower - run the test at the temperature you actually print at. Check the vat for leftovers afterwards; a Clean Resin Vat cycle picks up anything you missed.

### Advanced: your resin’s working curve (Jacobs)

The test strip holds more data than “which bar looks best”. Cure depth grows with the logarithm of exposure time - that’s why doubling the time doesn’t double the thickness, and why you judge bars by edges and holes, not by how thick they feel. If you want numbers:

1. Measure the thickness of at least 3–4 bars with calipers (skip broken ones).
2. Plot thickness against ln(seconds) (any spreadsheet; use the bar times from the table above). The points form a straight line - that’s the resin’s working curve.
3. The slope is Dp (how deep light penetrates); where the line crosses zero thickness is Ec (the minimum exposure that cures anything). Together: depth = Dp · ln(t / Ec).
4. Read your time: for reliable layer bonding you want the cure depth around 2× your layer height (0.1 mm for 0.05 mm layers) - find where the line reaches that thickness and use that time as Regular exposure.

💡 This is the same method resin manufacturers use to publish Dp/Ec - with a caliper and a strip you can characterize any unknown resin in one test.

### Boot animations

The printer can play a short animation on its screen at power-on - and you can swap it. Installed animations live on the SD card and are picked in two places:

- On the printer: System → Advanced → Display → Boot animation - OK cycles Default (the built-in logo), Shuffle and every installed animation.
- In the dashboard: Settings → the Display tab (it holds the boot animations and the 3D-preview options). Picking a row only stages the choice - press Save config to apply it. Show plays any installed animation on the printer’s screen right away (only while the printer is idle), and Delete removes its file from the SD card.

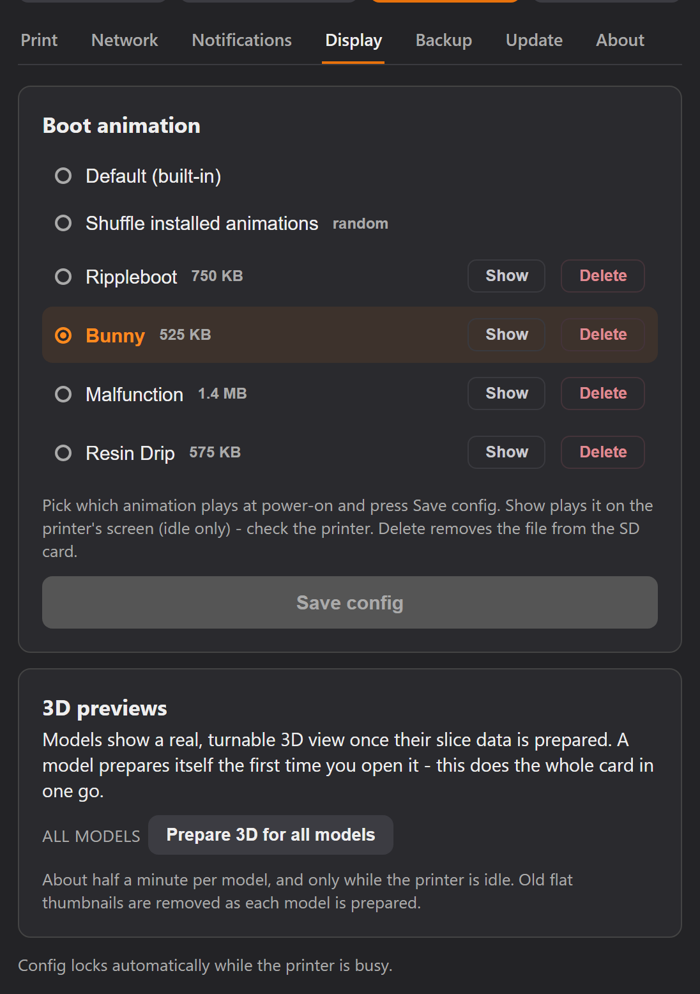
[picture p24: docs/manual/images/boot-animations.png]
Settings, Display tab: boot animations with Show and Delete, the staged selection, and Prepare 3D for all models


Shuffle (offered once two or more animations are installed) plays a random installed animation on every boot.

Getting new animations onto the printer:

- Default library: below the installed list, the Display tab shows a small library hosted on the project’s GitHub Pages - press Install and the printer pulls the file onto the SD card. Installing does not select it - pick it and Save config when you’re ready.
- From the community site: browse the animation library in the Connect tab and install from there (WiFi and Web control must be on).
- By hand: copy a .tmb animation file into the /bootanim folder on the SD card.

💡 Keep animations short - 2–4 seconds is the sweet spot. The firmware hard-caps playback at 250 frames or 10 seconds (whichever comes first), and pressing Back skips the animation immediately.

### 3D previews

The second card on the same Display tab has nothing to do with animations. A model can only be turned in 3D once its layers have been decoded, and that happens by itself the first time you open it - roughly a minute - after which the result is stored next to the model on the SD card and never has to be done again.

Prepare 3D for all models does the whole card in one go, so no model keeps you waiting later. It is quicker per model - about half a minute - because it prepares the lighter version that the list and the phone use; opening a model still fills in the full-resolution one. It runs only while the printer is idle and stops by itself if a print starts. Old flat thumbnails are replaced as it goes, which is the other reason to run it once after an update: the pictures in the model list are redrawn to match what the dashboard draws today.

Boot animations were contributed by Tanner Steorts (@Tann2019) (https://github.com/Tann2019); Shuffle by Brian Karmelk (@Briadark) (https://github.com/Briadark).

## 13Maintenance menu

The main menu’s Maintenance entry holds the three jobs that touch the hardware rather than a file: levelling the plate, moving it by hand, and curing the leftovers out of the vat. None of them need a computer.

⚠️ Know which way each one moves. Level Build Plate drives the plate down, towards the screen. Move Build Plate goes wherever you tell it. Picking the wrong one with a part still on the plate is the one mistake here that can damage the FEP film or the LCD.

### Level Build Plate

Homes the plate downwards until it sits flat on the screen, which is how the plate is squared up and its zero is set. The printer says so before it moves - a red screen reading “Plate must be EMPTY. Homing goes DOWN.”

- Take the printed part off the plate first, and take the vat out (or make sure levelling is what you actually want) - the plate is going to travel all the way down.
- Use it when prints stop sticking evenly, after you have removed or refitted the plate, or after transport.

⚠️ Never use Level Build Plate to rescue a print. After a power cut, with a half-finished part still hanging on the plate, the instinct is to reach for the levelling item to get the plate up and out of the way. It goes down instead, and presses the part into the film. To raise the plate use Move Build Plate, or the Lift plate only button on the Power restored screen (see Power-loss recovery). Found the hard way by a user, 2026.

### Move Build Plate

Drives the plate up or down by hand, in the step you pick: 0.1 mm, 1 mm or 10 mm. This is the tool for everything that is not levelling:

- Raising the plate after a power cut so you can look at the part or take it off.
- Getting the plate clear before pulling the vat out.
- Closing in on a position gently - 10 mm to travel, 1 mm to approach, 0.1 mm for the last bit.

Both ends of the travel stop themselves, and say so. Going up, the plate stops at the top of its travel and the screen reads Plate is at the top - press Up again and nothing happens, which is the answer, not a fault. That is also where the plate stands right after every print, because the finishing lift parks it there. Going down, the moment the plate reaches the endstop the printer takes that as its zero and shows Plate is home: the height it reports is trustworthy again, exactly as after a homing run.

💡 The ceiling applies only once the printer has homed - by a print, or by driving the plate down onto the endstop as above. Before that it has no idea where the bottom is, so it cannot know where the top is either, and it lets you move freely rather than guess. You can see which state it is in on the dashboard: Plate height reads not homed until there is a reference.

### Clean Resin Vat

Lights the whole screen for a set time, so everything left in the vat cures into one thin sheet you can lift out in one piece - instead of chasing hardened crumbs around with a spatula. Run it when you change resin, when a print has failed and left something behind, or before putting the printer away.

1. Take the build plate out and leave the vat in place with the resin still in it.
2. Maintenance → Clean Resin Vat. Set the exposure with the arrows - 30 to 60 seconds - and start. Longer means a thicker, sturdier sheet; thin resin needs the longer end.
3. Wait for it to finish, then lift the sheet by a corner and peel it out slowly. Gently flexing the vat pops it loose if it clings.
4. Wipe what is left with IPA and a soft paper towel, and check the film against the light: it should be clear, with nothing cured stuck to it.

⚠️ Nothing hard in the vat, ever. No blades, no metal spatulas, no scraping - the clear FEP film on the bottom scratches, and a scratched film prints marks into everything after it. If a sheet will not come loose, run another cleaning cycle rather than forcing it.

💡 Dry run makes this do nothing. While Dry run is on, the UV LED stays off everywhere, this cycle included: the screen lights up, the timer runs, and no resin cures. Turn it off first (System → Advanced → Resin → Dry run) if the sheet never forms. Cleaning exposures do count towards the LED’s recorded hours, exactly like printing.

🧤 Gloves on for all of this. Uncured resin irritates skin, and a cured sheet still has liquid resin under it. Dispose of the sheet with your cured waste, not down a drain.

## 14Updating the firmware and the slicer

🔒 Firmware flashing is blocked while printing, and the web paths need Web control on. (PrusaSlicer upload is separate and works any time.)

Two things update here, and they are separate. The firmware is the printer itself - installing one reboots it. The browser slicer is a module kept on the SD card: it carries its own version and its own install button, and updating it never reboots the printer or interrupts a print. Both live in the same pane.

Three ways to update the firmware:

- On the printer (no computer): System → Update shows the installed version and checks GitHub for the latest. If a newer one exists, the Install button lights up - press OK and the printer downloads and flashes it over WiFi.
- From the dashboard - Settings → Update: installed vs latest with an Install latest button, a version picker (install any released version; downgrades ask to confirm) and Choose & flash… for a firmware.bin file. Latest means the stable channel - the one the printer offers by itself. A beta appears only in the version picker, so no printer installs one unless you pick it.
- For developers: PlatformIO OTA via the tinymaker-ota environment (open System → Update on the printer first - that path keeps the strict gate).

The dashboard Settings > Update pane: installed vs the stable channel, version picker, file upload and the Slicer module card

Two comforts while updating: the printer also checks by itself - shortly after WiFi connects at boot it looks for a newer version and shows “Update available - Install / Later” on the screen (choosing Later offers to turn the check off; the switch lives in System → Advanced → Network → Boot update and in dashboard Settings). And when you start an install from the browser, the dashboard locks under an “Updating firmware” overlay and reloads itself when the printer is back - no guessing whether it finished.

The printer checks what it installs. Every release carries our own signature. Before an update from the internet is installed, the printer checks that signature against a key built into its firmware and activates the download only if it matches byte for byte. So it no longer matters which certificate GitHub shows in your region or what the printer’s clock says. If the check fails, nothing is installed: the automatic check reports Version check failed, and a version you picked is refused with Update refused - bad signature. Choose & flash… (a file you pick) and USB flashing still work.

✅ Don’t worry about a failed update. The printer keeps two firmware copies (dual OTA partition), so a failed flash falls back to the previous one. Just don’t power off mid-update.

The same Settings → Update pane also holds the Slicer module card (shown when the browser slicer is switched on): the version on the printer vs the latest published, an Install latest button and a version picker. It updates independently of the firmware - a slicer update never reflashes the printer.

While a print runs the card is locked, and the printer will not read it mid-layer - so the module card does not claim anything about what is installed: it says the card cannot be read now, and copying resumes when the print ends. The same is true of the backup check in the Backup tab.

### Backup & restore

Everything you have configured - print settings, device toggles, MQTT, even the lifetime print and UV LED counters - fits in one backup file. In the dashboard’s Settings → Backup tab:

- Download backup - saves tinymaker-backup.json to your computer.
- Backup to SD - stores the file on the printer’s SD card. Do this before a full USB reflash: the reflash wipes all settings, but on the first boot the printer finds the backup on the SD card and asks “Restore settings from SD backup?” - one press and everything is back. Settings shows when the SD backup was made, so you can tell at a glance whether it’s fresh.
- Restore from SD - applies the backup stored on the SD card at any time (the button is enabled only when one is present; while a print runs the card is locked, so the panel says it cannot check rather than claiming there is none).
- Restore from file - applies an uploaded backup at any time.

Auto backup to TinyMaker Connect (optional, for registered Connect users): a checkbox under Settings → Network → TinyMaker Connect keeps a backup on the Connect server after settings changes and after prints; the Backup tab then offers Download from Connect and Restore from Connect. Connect backups do not include the stored MQTT, notification or Connect secrets. When you register, save the recovery code (Retrieve / Copy buttons in the Connect section) - it restores your Connect profile if you ever reset the printer without a backup.

💡 WiFi credentials are managed separately (by the WiFi setup portal) and are not in the backup - after a full USB reflash you reconnect to WiFi once, everything else restores. The backup includes your MQTT password, so treat the file accordingly.

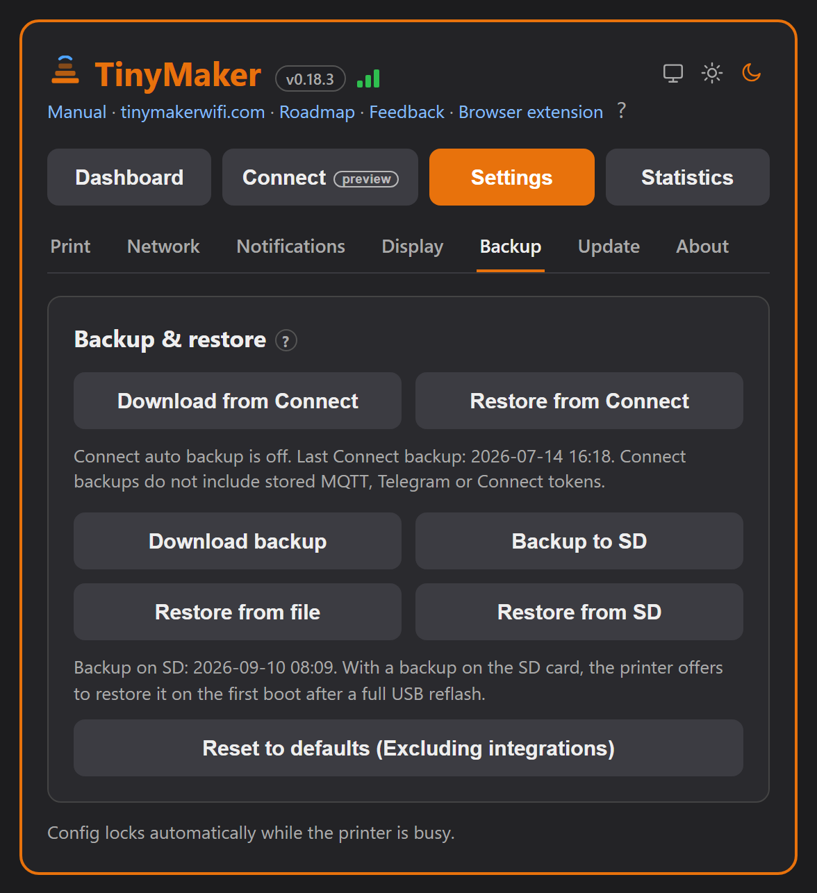
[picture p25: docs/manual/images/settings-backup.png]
The Settings tab with the Backup & restore buttons: Download backup, Backup to SD, Restore from file


## 15Home Assistant (MQTT) & notifications

Optional ways for the printer to reach you, all configured in the dashboard’s Settings tab (MQTT in the Network section, the messaging channels in Notifications).

### Home Assistant (MQTT)

Configure an MQTT broker and the printer publishes itself to Home Assistant with auto-discovery: print state, current layer, resin used, resin left + a low-resin alert, and run/remaining time - all as HA sensors you can put on dashboards or automate notifications on.

### Phone notifications - pick a channel

No Home Assistant? The printer can message you directly when a print finishes (with the print time and resin used), pauses for a low-resin refill, is canceled, or when power comes back after an outage interrupted a print. In Settings → Notifications there is one choice - Off / Telegram / WhatsApp / Discord - each channel with its own ? setup help and a Send test message button.

Telegram is the one used daily here. WhatsApp and Discord ship untested - they run on your own CallMeBot key or channel webhook, so testing them with our setup would prove nothing about yours. If you try one, tell us how it went (https://tinymakerwifi.com/feedback/) - working or not, both are useful.

Did the last message actually arrive? Under the channel picker the dashboard shows the result of the printer’s last automatic message - “Last automatic message: delivered 5 min ago”, or NOT delivered with the reason. It says automatic on purpose: Send test message takes a different path, so “the test works but nothing arrives while printing” is itself a useful clue - usually a token or chat id that is fine for a test but blocked when the printer is busy. The line stays hidden until there has been an automatic message to report on.

⌚ On a Wear OS watch: the separate TinyStatus app shows the progress ring, time left, layer and resin left on your wrist and buzzes when a print ends or the resin runs low. It only reads the printer and needs no setting here - how to get it (https://github.com/slibbinas/TinyMakerWifi#on-your-wrist-tinystatus).

### Telegram

Setup takes two minutes - the same steps are shown inline in the dashboard (the ? help next to the Telegram choice):

1. Create a bot: in Telegram, message @BotFather (https://t.me/BotFather), send /newbot, follow the prompts, and paste the token into Bot token (Settings → Notifications → Telegram).
2. Open your new bot and press Start (or send it any message) - a bot can’t message you until you do.
3. Get your Chat ID: open a chat with @userinfobot (https://t.me/userinfobot) - a separate bot, search “userinfobot” in Telegram - and press Start; it replies with your numeric Id, which is your Chat ID. (For a group, add @RawDataBot to the group and use the negative id it prints.)
4. Save config, then press “Send test message” - it should arrive within a few seconds.

🔒 The bot token is a secret - the dashboard never shows it back, only its last four characters (ends in XXXX), and it is included in your settings backup, so treat the backup file accordingly. The printer talks directly to Telegram over HTTPS; nothing goes through third-party servers.

### WhatsApp (via CallMeBot)

WhatsApp messages go through the free CallMeBot gateway - a one-time activation from your phone:

1. Open callmebot.com → WhatsApp text messages and add the bot’s current phone number to your contacts.
2. Send it the message “I allow callmebot to send me messages” from your WhatsApp.
3. It replies with your personal API key - enter it in Settings → Notifications → WhatsApp, together with your phone number (with country code).
4. Save config, then Send test message.

💡 Unlike Telegram, WhatsApp messages travel through the CallMeBot gateway (a third-party service) - that is what makes a bot-free WhatsApp setup possible.

### Discord (webhook)

Discord needs no bot at all - just a channel webhook:

1. In your Discord server open Server Settings → Integrations → Webhooks.
2. New Webhook - pick the channel the printer should post to, then Copy Webhook URL.
3. Paste the URL in Settings → Notifications → Discord, Save config, then Send test message.

🔒 The webhook URL is a secret - anyone holding it can post to that channel. The printer talks to Discord directly.

## 16Troubleshooting & FAQ

### The printer won’t connect to WiFi

After 15 s it boots offline - SD printing still works. To retry, reset WiFi (System → WiFi Info → OK, or hold Back while powering on) and set it up again.

### Where do I find the printer’s IP address?

System → WiFi Info on the printer - it always shows the connected network, signal strength and IP. (The boot screen only shows the IP after the first-time portal setup; on routine boots the signal bars just turn green.) On most networks tinymaker.local works instead of the IP.

### What SD cards work?

Format the card as FAT32 and keep it 32 GB or smaller - exFAT and NTFS aren’t read, and cards larger than 32 GB can’t be FAT32 without reformatting. A class-10 card is plenty. Copy .sl1/.zip archives into the card’s root (not a sub-folder).

### PrusaSlicer “Test” fails

Check the printer is on and shows a green dot / an IP under System → WiFi Info. Use that IP if tinymaker.local doesn’t resolve on your network. The API key value doesn’t matter.

### The dashboard opens but every button is disabled

Web control is off. Turn it back on on the printer: System → Advanced → Web control. (Slicer upload and MQTT are unaffected by this switch.)

### My print looks half-height, flat or squashed

Slice with the 0.05 mm profile. At a 0.10 mm setting the printer uses every other image by design. If parts come out flat or the wrong height, open PrusaSlicer’s Print settings and confirm the layer height actually reads 0.05 mm - a PrusaSlicer update or picking the wrong preset can silently reset it, and the printer can’t tell from the file, so it just prints wrong without a warning.

### “Resin left” looks wrong

It’s an estimate that only counts confirmed refills. Press Set VAT full after a full refill, and keep Ask refill on so it stays honest.

### What do I do after a print? (washing & curing)

Parts come off the plate wet and only partly cured. Rinse them in isopropyl alcohol (IPA) - two baths help: a dirty one first, a clean one second - then let them dry. Only then UV-cure them (sunlight or a curing station) until hard. A matte, chalky surface is usually over-curing or too much sun - cure in shorter bursts and check often. Always wear gloves; uncured resin is a skin irritant.

### How do I clean the resin VAT?

When changing resin or storing the printer, pour the resin back through a paint filter into its bottle, then wipe the VAT with IPA and a soft paper towel - never anything hard: the clear FEP film on the bottom scratches easily. Held to the light the FEP should be clear, with no cured skin or cloudiness stuck to it; gently flexing the VAT pops leftover cured bits loose so you can peel them off by hand, not with a scraper.

### The web flasher stops with “ERROR: Timeout”

Almost always the transfer speed, not the browser: set the flasher’s Baud rate to 115200 and flash again. Cable, hub and driver checks are in Installing the firmware.

### The printer says the model is too wide

The model was sliced for a different printer: its layers are wider than the TinyMaker’s 320 px screen. The printer refuses it before starting - on its screen and in the dashboard - instead of printing garbage. Re-slice it with the TinyMaker profile (PrusaSlicer) or in the dashboard’s built-in slicer.

### A firmware update failed

The dual OTA partition keeps the previous firmware, so the printer should still boot. Try again from System → Update, or upload a firmware.bin from the dashboard’s Settings → Update.

If the printer says Update refused - bad signature, the version you picked did not match its release signature - nothing was installed and the current firmware keeps running. On 0.18 or newer, “Version check failed” means the printer could not fetch the update list or could not verify it; check the printer’s internet connection and try again later. If either persists, download firmware.bin from the Releases page (https://github.com/slibbinas/TinyMakerWifi/releases) and use Choose & flash….

A printer on firmware older than 0.18 that is stuck on “Version check failed” (in some regions GitHub serves a certificate that older firmware rejects) needs one update by hand: Settings → Update → Choose & flash… with the firmware from the Releases page (https://github.com/slibbinas/TinyMakerWifi/releases), or the browser flasher over USB. After that one step it checks our own signature instead, and updates on its own again.

### How do I keep my settings through a USB reflash?

Before flashing: dashboard → Settings → Backup to SD. After the reflash the printer finds the backup on the SD card and offers to restore it on first boot. Only WiFi needs to be set up again.

### What is TinyMaker Connect, and do I need it?

No, you do not need it - everything in this manual works without it. Connect is an optional online service (built by Brian Karmelk (https://github.com/Briadark)) that the printer can register with. What it adds: your settings backed up off the printer, a recovery code to get that profile back after a factory reset, and a way to share a model from the preview. It is switched on in Settings → Network → TinyMaker Connect; until you register, the Connect tab is not even shown. Leaving it off costs you nothing but those extras.

### Can I reach the printer when I am not at home?

The dashboard is LAN-only and has no password - anyone who can reach the address can start and stop prints. So there are two safe ways and one that is not:

- TinyMaker Connect - the printer connects outwards to the service, so nothing on your router has to be opened.
- A VPN into your own network (Tailscale, WireGuard, your router’s own VPN) - your phone joins the home network from anywhere and the dashboard works exactly as it does at home. Nothing of ours is involved.

⚠️ Do not port-forward the printer to the internet, and do not point a dynamic-DNS name at it. There is no login to stop anyone who finds it - and what they find is a machine that cures resin with a UV light. If you want access from outside, use one of the two ways above.

### How do I go fully offline?

System → Advanced → WiFi → Off. The printer behaves like the original firmware; turn WiFi back on in the same place whenever you like.

### What does the “Anonymous usage ping” send?

Once per firmware version - on the first boot after a flash - the printer sends three things: a one-way hash of its factory MAC address (so each printer is counted once, without being identifiable), the firmware version, and the lifetime print hours. It feeds the “N printers running TinyMakerWifi” counter.

If the printer restarts unexpectedly or dies in the middle of a print, it also sends a short crash report: the same hash, the firmware version, why it restarted (crash, watchdog, power dip…), the layer the print stopped at and roughly when, and - after a crash - the program addresses where it happened plus a fingerprint of the exact firmware build. That is what lets a rare fault be found and fixed instead of guessed at.

Nothing else, ever - no models, no settings, no network details. One switch turns both off: untick Settings → Network → Anonymous usage ping.

## Credits

TinyMakerWifi - the WiFi, wireless-upload and over-the-air-update firmware described in this manual - is created and maintained by Viktoras Šidlauskas (@slibbinas (https://github.com/slibbinas)): the WiFi stack, wireless upload, OTA self-update, the 3D model preview & live print progress, and the resin estimation & VAT tracking.

- The initial web dashboard, the Advanced menu (WiFi & Web-control switches), the web flasher, safe model imports and TinyMaker Connect (with auto-backup & recovery) - contributed by Brian Karmelk (@Briadark) (https://github.com/Briadark).
- Boot animations (the on-device library, playback and one-click install) - contributed by Tanner Steorts (@Tann2019) (https://github.com/Tann2019).
- The browser slicer’s engine is PrusaSlicer’s libslic3r 2.9.6 (© Prusa Research a.s.), compiled to WebAssembly from the unmodified upstream sources - tag version_2.9.6, commit b028299 - and used under the GNU AGPL-3.0. Everything else in TinyMakerWifi stays MIT-licensed; the two are separate programs that ship side by side.
- Original TinyMaker firmware & printer - by the TinyMaker3D Team (https://tinymaker3d.com/).
- Additional fixes, testing and ideas from the TinyMaker community.

The firmware is MIT-licensed; the TinyMaker hardware is CC BY-NC-SA 4.0. If TinyMakerWifi is useful to you, you can buy me a coffee (https://paypal.me/Sidlauskas?locale.x=en_US&country.x=LT) - thank you!

The dashboard asks once as well: after the third print that ran to the end with the UV on, a small dialog offers a few amounts (plain links to the same PayPal page) or No thanks. It appears once per printer, never again, and the printer never learns what you chose. Failed prints and dry runs do not count.

Close

TinyMakerWifi · User Manual · v1.0.1 · by Viktoras Šidlauskas · tinymakerwifi.com
Based on the open-source TinyMaker 3D printer (https://tinymaker3d.com/). Firmware MIT-licensed.

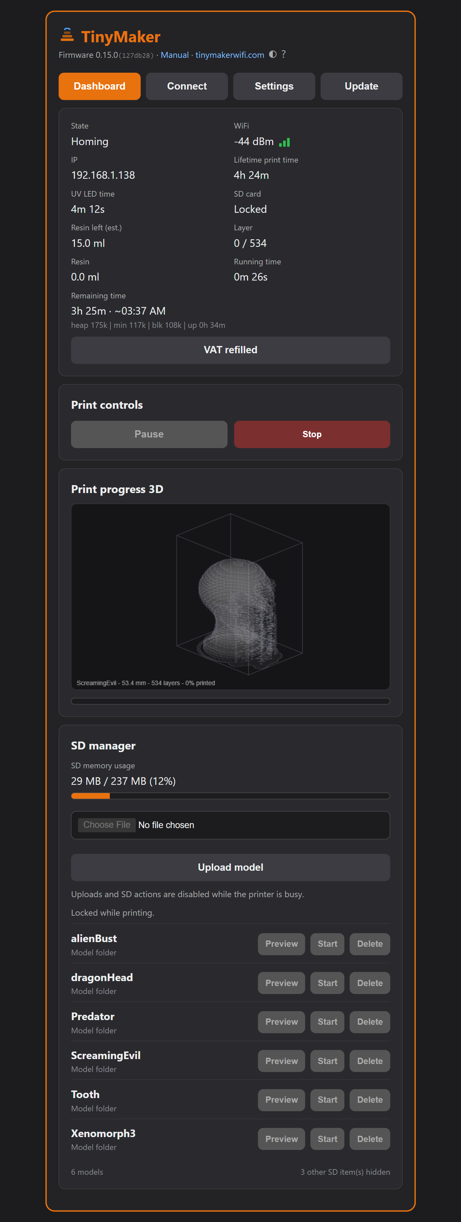
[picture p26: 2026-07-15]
Images/screenshots/dashboard-print.png

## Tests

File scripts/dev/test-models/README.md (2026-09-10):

# Testiniai modeliai

Trys mažyčiai spausdinimo darbai, skirti **firmware eigai tikrinti**, o ne detalėms
gaminti: startui, pauzei, stabdymui, pabaigai, skaitikliams. Su jais nereikia leisti
50 min spaudinio tam, kad pamatytum, kaip elgiasi vienas pranešimas.

**Vardas sako trukmę** - tiek jis realiai ir užtrunka, tad rinkiesi ne spėliodamas:

| Modelis | Sluoksnių | Realiai | Printerio spėjimas |
|---|---|---|---|
| `Test2min.zip` | 4 | ~2 min 20 s | 1m 38s |
| `Test4min.zip` | 9 | **4 min 20 s** (išmatuota) | 3m 03s |
| `Test10min.zip` | 28 | ~10 min | 8m 26s |

⚠️ **Printerio spėjimas nuosekliai per mažas.** Trumpiems modeliams paklaida didžiausia
(+42%), nes juose dominuoja ilgos bazinių sluoksnių ekspozicijos; ilgesniems ji mažėja
(173 sluoksnių Ziedui buvo +14%). Vardai remiasi tikra trukme, ne tuo spėjimu.

## Iš ko jie padaryti

Tai **tikri Ziedo apatiniai sluoksniai**, nuskaityti iš paties printerio:

```
GET /api/files/layer?name=Ziedas&i=<N>&source=1
```

Tas endpoint'as atiduoda sluoksnio PNG tokį, koks jis guli SD kortelėje - **320×240**,
nes tokia ir yra šio spausdintuvo kaukės ekrano skiriamoji geba. Todėl formato spėlioti
nereikėjo: jis toks pat, kokį duoda sliceris. Spausdinasi žiedo apačia, plokščias
žiedelis 0,2-1,4 mm aukščio.

## Kaip įkelti atgal

Vienas failas, viena komanda (tas pats kelias, kuriuo siunčia PrusaSlicer - pulto kilmės
jam nereikia):

```bash
curl -F "file=@Test4min.zip" -F "source=test" http://<printerio-ip>/upload
```

Atsakymas `{"ok":true,"queued":true,"name":"Test4min"}` reiškia, kad archyvas priimtas ir
išpakuojamas. Kelis modelius kelti **po vieną**: kol vyksta išpakavimas, printeris atsako
`{"error":"printer busy"}`.

## Ko čia nėra ir kodėl

**Peržiūros paveikslėlio.** Išpakuotojas iš archyvo ima tik sluoksnius (skaičius prieš
`.png`, žr. `src/Import.ino`), o `POST /api/files/model/preview` per `curl` atmeta
(`preview upload failed`). Todėl sąraše modelis iš pradžių būna be piktogramos - ji
atsiranda pati, kai modelį kartą atidarai pulte.

Kilmė: 2026-09-01, V prašymu, kad kiekvienam bandymui nereikėtų ilgo spaudinio.
Pirmieji vardai buvo `ShortTest`, `TestasLong` ir `TestasMini`; pakeisti tą patį vakarą,
nes iš jų nesimatė, kuris kiek trunka.

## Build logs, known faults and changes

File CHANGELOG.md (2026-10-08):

# Changelog

All notable changes to **TinyMakerWifi** - the WiFi / wireless-upload / OTA
firmware for the open-source TinyMaker MSLA resin printer. Written for humans:
skim it to see what each version added and who contributed what, without
digging through pull requests.

Versions use the fork's own SemVer (`FIRMWARE_VERSION` in `platformio.ini`);
the upstream TinyMaker3D firmware is `1.0.2`. Format follows
[Keep a Changelog](https://keepachangelog.com/). Full release assets are on the
[Releases page](https://github.com/slibbinas/TinyMakerWifi/releases).

Credits: features are by **Viktoras Šidlauskas ([@slibbinas](https://github.com/slibbinas))**
unless noted. Community contributors are tagged inline.

## [1.0.1] - 2026-10-08

A sturdier update path - three fixes from the review before 1.0.0.

- **A firmware that fails to start rolls back by itself.** The printer already kept the
  previous firmware, but marked a new one as good before it had even started, so a version
  that crashed while starting would have restarted forever until a USB reflash. Now a new
  firmware counts as good only after it has run for a minute; if it crashes or loses power
  before that, the printer starts the previous firmware again. A restart you ask for (Reboot,
  WiFi or factory reset) is not a failure and keeps the new version. It works with or without
  WiFi, and protects 1.0.1 itself.
- **No false "checksum mismatch" right after a release.** For the first minutes after a new
  version is published, the download servers could hand out the new description with the old
  file, and the update failed as a checksum mismatch. The printer now downloads the file named
  after the version, which never changes. This helps updates from 1.0.1 onwards.
- **A steadier download.** The buffer used while an update is fetched no longer sits on the
  same small stack as the secure connection. This too helps updates from 1.0.1 onwards.

## [1.0.0] - 2026-10-08

The first stable release. 1.0.0 is 0.18.6 - in beta since 2026-10-02 - with only the
version number changed, and it goes out on the automatic update channel to every printer.

- **Drag-and-drop upload for everyone.** Until now it was in the 0.18.6 beta only: drop an
  STL on the slicer block, or an SL1/ZIP on the SD manager.
- **What 1.0 means here:** the features have been frozen since 2026-09-24. From now on 1.0.x
  carries fixes only; new features go to 1.1.
- **Documentation matches the firmware:** the README, the user manual (drag-and-drop, models
  sliced too wide, the power-restored message, stable vs beta, update troubleshooting), the
  LAN API notes and the hosting notes (#283).

Coming from 0.17 or older? The 0.18 line added signed self-updates (0.18.0), crash reports
with a backtrace (0.18.1) that name the exact build (0.18.3), owner links and the three-way
theme switch (0.18.3) and a refusal of models sliced for a wider screen (0.18.4) - see the
entries below.

## [0.18.6] - 2026-10-02

Drag and drop a file onto the dashboard. Beta: pick it in the dashboard's Update tab - the automatic update channel stays on 0.18.5, so no printer updates itself for this one.

- **Drag-and-drop upload.** Drop an STL on the slicer block, or an SL1/ZIP on the SD manager,
  to load or upload it - the same as the Choose STL / Upload buttons. While dragging, a neutral
  grey frame marks a block that accepts the file; on drop a valid file briefly flashes orange and
  is loaded/uploaded (expanding the block if it was collapsed), a wrong one briefly flashes red
  and is ignored (#268).

## [0.18.5] - 2026-09-30

A picture for models printed straight away.

- **The printing model now shows its list icon in the dashboard and the browser extension
  even when it has no saved 3D render.** A model started before its 3D preview finished
  building had no render on the card, so mid-print neither the dashboard (reopened on another
  device) nor the Chrome extension showed any picture - the small SD-list icon lives only on
  the card and the card is off-limits while printing. It is now snapshotted into RAM at print
  start and served from there, so render-less models (a dummy, a quick test print) get a
  thumbnail during the print too (#262).

## [0.18.4] - 2026-09-29

A crash fix and better crash reports.

- **A model that is too wide is refused instead of crashing the printer.** A layer image
  wider than the 320 px screen (a model sliced for a different printer) used to overrun an
  internal buffer and reboot the printer mid-print. Now the printer says the model is too wide
  and to re-slice it for TinyMaker, both on its screen and in the dashboard, and never starts
  such a print. The layer drawing is also hard-capped so it can never overrun.
- **Crash reports say where the stack was.** A crash report now also carries the stack
  pointer at the moment of the crash and where the main loop's stack lies, so a crash inside
  the exception handler itself (seen once on 0.18.3) can be told apart as a stack overflow or
  a corrupted stack. Still anonymous: processor registers and addresses only, nothing about
  you or your models.

## [0.18.3] - 2026-09-24

Small dashboard improvements and more useful crash reports.

- **Light, dark or system theme.** Three icons in the dashboard header - *System* follows
  your phone or computer, *Light* and *Dark* stay put. The Manual, Feedback and Roadmap
  links open in the same theme.
- **"Browser extension" link in the header.** It leads to the TinyMaker browser extension
  (print progress on the toolbar) and disappears by itself once the extension is installed.
  The extension itself (0.1.4, separate download) now follows your theme too.
- **Your own links in the header.** Put a `links.json` file on the SD card and its entries
  show up next to Manual and Feedback - handy for a shop, a school or a maker who wants
  their support page or resin list one tap away. Without the file nothing changes.
  See [the API notes](docs/api.md) for the format.
- **Getting started no longer requires PrusaSlicer.** The step now reads *Slice - built-in
  slicer or PrusaSlicer*: the browser slicer in the dashboard is enough, PrusaSlicer stays
  an option.
- **Crash reports now say exactly which build crashed.** A report carries a fingerprint
  of the firmware build that crashed and of the one sending it, so a self-built copy is
  told apart from a release. Its reason, layer and time are now that crash's own - before,
  a printer that had once died mid-print repeated that old event in every later report.
  The README and manual now also describe the crash reports, which share the usage-ping
  switch.

## [0.18.2] - 2026-09-22

The boot crash the telemetry found is fixed.

- **A rare crash on start-up is gone.** On some printers the WiFi setup step could
  hit a bug while closing its setup screen and make the printer restart itself once
  at power-on (or take a couple of tries to get online). It never affected prints.
  0.18.1's crash reports pinned it to the exact line on the first report, and this
  release fixes it. (For the curious: a null check in the WiFiManager library's
  portal shutdown.)

## [0.18.1] - 2026-09-22

Better crash reports, so a rare freeze can actually be found and fixed.

- When the printer reboots from a crash, it now sends an anonymous **backtrace**
  (which function and line), not just "it crashed". This is what lets a rare
  fault be located and fixed instead of guessed at. As before, it is opt-out and
  carries no personal data.

## [0.18.0] - 2026-09-22

Self-update no longer depends on GitHub's certificate.

- **"Version check failed" fixed for good, wherever you are.** Some printers - it
  turned out, depending on region - could not check for or install updates and
  showed *"Version check failed - could not reach GitHub"*, even with a working
  connection. The printer was verifying GitHub's certificate, and in some regions
  GitHub serves a different one. Now the printer verifies **our own signature** on
  each update instead, so the region (and the printer's clock) no longer matter.
- **How it reaches you:** printers that can currently update will get 0.18 the
  usual way. A printer that was stuck on "Version check failed" needs to be updated
  **once by hand** - Settings → Update → *Choose & flash…* the 0.18 firmware from
  the Releases page (or the browser flasher over USB). After that one step,
  automatic updates work normally again, for good.
- Under the hood: updates are signed with a private key and verified against a
  public key built into the firmware; the image is streamed to flash and installed
  only if its signature and checksum match.

## [0.17.9] - 2026-09-22

While a print runs, the slicer and SD cards fold away, and there is a small Chrome
extension that shows the printer on the browser toolbar.

### Added

- **TinyMaker status - the printer on your browser toolbar** (Chrome extension, preview).
  The icon shows the print progress (`42%`), `II` when paused, a tick when a print has
  finished and `!` when the printer does not answer. Click it for the layer, time left and
  finishing time, resin used and left, and a button that opens the dashboard - or switches
  to it, if it is already open in a tab. It only reads the printer's status once a minute and
  never changes anything. Not in the Chrome Web Store yet, so for now it is installed by hand.
  [Read more](https://github.com/slibbinas/TinyMakerWifi#on-the-browser-toolbar-tinymaker-status-chrome-extension-preview)
  (#208, #209, #211).

### Changed

- **While printing, the slicer and SD cards are folded and locked.** Only their grey headers
  stay, on the phone as well as on a computer. When the print ends, the SD card opens again (#207).
- **The first visit opens the SD card**, not the slicer. Once you pick a card, the dashboard
  remembers your choice (#207).
- **With the slicer open, the folded SD card shows only its header and the space bar** (how
  many files, how much space is left). Upload is on the open SD card (#207).

### Fixed

- **A locked card's header no longer turns orange under the pointer**, and during a print the
  preview title is no longer a link to the folded SD list (#207).
- **Deleting a small model no longer hangs on "starting…".** The printer removed it before the
  dashboard's next status check, so the message stayed and the model stayed in the list until
  a reload. It now ends with *Deleted* and the list updates (#213).

## [0.17.8] - 2026-09-19

The browser slicer can now slice **without supports**, and **Size keep** keeps your size.
Switching between the slicer and the SD card no longer loses what was on screen.

### Added

- **Supports: no** (slicer module 3.6.2). For a part that is already flat or comes with its
  own supports from another program: nothing is added and the part is printed the way it
  sits in the file, only turned on the plate to fit. The raft is off by default; pick a raft
  size and it rings the base of the part. With a module older than 3.6.2 on the printer the
  option stays locked and the card says where to update it (#202).
- **Parts that start in mid-air are flagged** when slicing with no supports, so a missing
  support is seen before the print, not after it (#202).

### Changed

- **Size keep keeps the size.** When only the supports reach past the plate, the slicer no
  longer shrinks the part - it keeps your size and warns that the edge supports will be cut.
  A part whose own outline does not fit is still scaled down (#202).

### Fixed

- **The SD model stays when you switch to an empty slicer and back.** Opening the slicer
  with no STL loaded used to forget the SD model you were looking at; it now comes back
  when you return to the SD card. The preview title follows the card: *Slicer preview*
  over the slicer, the model's name over the SD card (#203).
- **The slicer's view keeps its buttons while an SD preview loads in the background.**
  Leaving an SD preview before it finished loading hid **?**, the pan and rotate keys and
  the zoom corner on the slicer's view until the load ended, and **Share** switched on in
  the slicer view, offering to share the SD model instead of the part on screen (#203).
- **The flat layer view keeps its shape on a phone.** In the enlarged preview on a narrow
  screen the 2D and UV layer views were squashed to about half their width - a round part
  showed as an ellipse. The plate now fits the window both ways and keeps its 4:3 shape (#205).

## [0.17.7] - 2026-09-19

A fix for the SD list on a computer screen.

### Fixed

- **The SD list no longer flickers between pages.** A model with a long name that
  had just appeared on the card (marked **New**) could wrap into three lines. When
  it sat at the top of a page, the list shrank to three rows per page, and pressing
  **Next** made it jump back and forth between two pages many times a second. Model
  names now stay on one line - cut with "…" only when they do not fit, full name on
  hover - and the **New** mark sits at the end of the date line, so every row is the
  same height.

## [0.17.6] - 2026-09-18

The browser slicer is **on by default**. Until now it shipped switched off, so only
the people who went looking for the switch ever found it - and the whole point of
slicing on the printer's own page is that it is there when you need it.

### Changed

- **The slicer is on from the start** (plan K9). A fresh printer shows the **STL
  slicer** card straight away, with nothing to switch on first.

  **Printers upgrading from 0.17 get it switched on once.** Their stored answer is
  almost never a real choice: 0.17 defaulted to off and wrote that "off" on every
  settings save, so a new default alone would have changed nothing for them. The
  switch-on happens exactly once, and after it your own answer stands - switch it
  off and it stays off, across updates. Settings backups made from now on carry
  that distinction, so restoring one after a full reflash no longer turns the
  slicer off for good.

- **Docs follow:** the README and the manual no longer tell you to switch the
  slicer on first, and say where to switch it off instead.

### Also in this release

- Slicing in the browser no longer loses the progress line when the window
  changes size mid-job (a phone doing that on every scroll), and when the engine
  slices the part again it says which pass it is and why (#177).
- The printer's own folders on the SD card can no longer be replaced by a model
  named after them (#172), and a model can no longer be imported over one (#175).
- The dashboard does not say "Printer busy" while the slicer is showing its own
  progress (#174); in the slicer view the shape tools step aside while a fit or a
  lay-flat runs (#173), and the card says what to do when the slicer module is
  not on the card and there is no internet (#171).
- Resin **Buy** links say that they are affiliate links (#168, #169).

## [0.17.5] - 2026-09-16 (beta)

Two things. The self-update now checks that it is really talking to GitHub before it
flashes anything - the most important security fix since WiFi arrived, contributed by
[@DeadlySIn777](https://github.com/DeadlySIn777). And once, after your third print that
actually came out, the dashboard says thank you and asks - a single time, and never
again - whether the firmware is worth a few euros to you.

### Security

- **The self-update checks who it is talking to** (by
  [@DeadlySIn777](https://github.com/DeadlySIn777), #146). Until now both the version
  check and the firmware download skipped the certificate check, so on a hostile
  network - a café, a shared flat, a compromised router - anyone answering as GitHub
  could hand the printer a firmware of their own, and the printer would flash it and
  reboot into it. Both now verify GitHub's certificate, and the printer only flashes
  files from our own release folder: a forged `version.txt` can no longer point it
  anywhere else. If the check fails, the update stops and the printer says so -
  **Choose & flash** in the dashboard's Update tab and USB flashing keep working.
- **Room for GitHub to change certificates** (#166). The printer now also trusts Let's
  Encrypt's ECDSA roots, so a change on GitHub's side cannot quietly take self-update
  away from printers in the field.

  Tested on the printer: the version check, a real install through the verified
  connection, rejected bad version strings, the slicer module check, and free memory
  before and after.

### Added

- **A thank-you note after the third good print.** The printer counts prints that ran
  to the end with the UV on; the third one brings up a small dialog in the dashboard
  with three amounts and a link for any other amount. Each button is an ordinary link
  to a payment page - the printer never learns whether you paid, or whether you opened
  the link at all, and the note does not come back either way.

  **Why the third and not the first:** the first print is usually a test, and later
  ones can still fail. Three that came out mean you came back on your own. A failed
  print does not move the counter, so nobody is asked after a bad evening. If you
  press **No thanks**, that is the end of it - the dialog is shown once per printer.

### Changed

- **`/api/status` reports two more fields** (`printsOk`, `thanksSeen`), and a new
  `POST /api/thanks/seen` marks the note as shown. Both are ordinary dashboard API
  calls behind the usual web-control and busy guards; if you drive the printer from
  your own scripts, nothing you already use changed.

## [0.17.4] - 2026-09-15 (beta)

A slicer card update for the 0.17 beta: you now choose how the slicer places a part on
its own, and switching between the slicer and the SD card no longer leaves pieces of
one on the other. The firmware core is unchanged; everything here is in the dashboard.
It only matters if you switched on **Settings → STL slicer in the dashboard**.

### Added

- **Fit by and Size.** Two new switches under the slicer settings decide how a part is
  placed. **Fit by:** *flat* lays it on its widest side, *supports* tilts it so it
  needs the fewest supports. **Size:** *keep* leaves your size and scales down only
  when it does not fit, *max* makes the part as large as the plate allows, up to 300 %.
  They apply at once to the model you have loaded, to every STL you load next, and to
  the orange button when a part does not fit; the card says how much the part was
  scaled. **Reset to defaults** puts them back to flat and keep.

### Changed

- **One Fit button on the 3D view instead of two.** "Fast fit" and "Optimal fit" are
  replaced by a single **Fit**, which places the part the way Fit by and Size say -
  handy after turning it by hand. The orange button is named after Fit by: "Fit flat"
  or "Fit for supports".
- **A thin line above Fit by and Size** sets them apart from the settings that change
  the slicing itself.
- **The ? help button always stands first in the corner of the 3D view**, and the
  defect marking tool sits next to it.

### Fixed

- **The slicer's shape tools no longer stay on the SD preview.** After loading an STL
  and opening the SD card, the Fit, Lay flat, Flip, Tilt, Rotate and Scale buttons
  stayed on top of the SD model, and pressing one jumped back into the slicer.
- **The preview title comes back with the slicer.** Returning from the SD card to a
  sliced part kept the SD model's name above the slicer's result.
- **No empty row above the view buttons on the SD side.** They now move back up when
  the shape tools leave.
- **The camera frames the slicer's part again after a visit to the SD card.** It used
  to stay where the SD model had left it, often so close that the plate filled the
  whole view.

## [0.17.3] - 2026-09-15 (beta)

An important optimization for the 0.17 beta: the dashboard no longer rushes a printer
that is busy printing.

This is a small printer with a small heart - the same loop that times the UV exposure
and drives the Z motor also answers the network. While a layer cures it does not answer
the network at all; it catches up between layers and during lifts. Since 0.17.0 the
dashboard gave it only 4 seconds to answer, which was far too strict for that rhythm: a
longer layer made two answers in a row come late, and the dashboard showed "Syncing
with printer at the next safe network window..." during perfectly normal prints. The
printer itself was fine the whole time.

The firmware core is unchanged; this is the dashboard that ships inside it.

### Changed

- **The wait is now automatic and follows the print.** While printing, the dashboard
  waits as long as the longest exposure in your settings plus 10 seconds, and never
  less than 20 seconds, so base layers that cure for a minute are covered too. An idle
  printer still has to answer within 4 seconds, so an upload from PrusaSlicer is still
  explained right away.
- **A slow network can be given more time, and the dashboard tells you where.** If the
  printer keeps answering late anyway - for example when the phone or laptop reaches it
  through a WiFi extender - the message now says the printer answers slowly on this
  network and points to **Settings > Network > Wait while printing**. The value is kept
  in that browser only, because the delay belongs to the network that device is on; 0
  keeps it automatic.

## [0.17.2] - 2026-09-13 (beta)

A slicer fix-up for the 0.17 beta. The firmware itself is unchanged; everything here is
in the dashboard's slicer card and in the slicer module it loads. It only matters if
you switched on **Settings → STL slicer in the dashboard** - the slicer stays off by
default until 1.0.0.

This release also pairs the dashboard with slicer module 3.5.0, which is already
published. A 0.17.1 dashboard can install that module, but it was built for an older
one and does not know how the new module decides whether a part fits.

### Changed

- **Parts get more of the plate.** The slicer used to keep 3.1 mm clear on every side
  of the whole model - the room a support foot and the pad rim need - so a part could
  use only 68 % of the plate and was scaled down for no measured reason. The margin is
  now 1.0 mm, measured on a printed edge coupon (the screen cures to within 0.5 mm of
  its lit edge; the rest is the plate's sideways play). Usable area goes from 68 % to
  89 %.
- **The fit check happens after the supports exist.** Instead of guessing from the
  worst case, the slicer now measures the real footprint of the part with its supports
  and pad. Only if that really reaches past the plate is the part sliced again, smaller
  by exactly what is needed.
- **Heavy models are laid down faster.** For parts with 150 000 triangles or more, the
  careful placement search is split across up to four workers (never on a device with
  under 4 GB of memory). A 300 000 triangle bust went from about 4.8 s to 1.5 s, with
  the same result.

### Fixed

- **A part scaled down to fit is now said out loud.** The card shows "Scaled down N% -
  the supports reached past the plate.", and if the part still overhangs after that, it
  says so and asks you to scale it down by hand. The scale slider and the height field
  move to the new size, so the next nudge does not push the part back past the edge.
- **The size line under the file name follows that scale-down.** It kept showing the
  size from before, so someone printing a part that must be a real size (a ring, a
  bracket on a shaft) read the old numbers and got a smaller part.
- **The percent field's up arrow grows the part again.** It did nothing anywhere; the
  down arrow worked.
- **Discard stays on the right when the result line is long.** When a part still
  overhangs after the scale-down, the longer message pushed the Discard button onto its
  own line on the left. The message now wraps in its own column.
- **A clean card asks for slicer module 3.5.0.** A card that already had a module
  installed was not affected - the installed one is always used.

## [0.17.1] - 2026-09-12 (beta)

### Fixed

- **A dashboard Stop pressed while the plate rose into a pause showed "Paused".** The
  print did stop, but once the plate reached the pause height the pause was parked
  anyway: for the ~24 s final lift the dashboard said "Paused" with **Resume** live and
  the printer screen showed the pause icons (a resin pause would also have sent its
  refill message to Telegram). A stopped print now stays "Canceling..." to the end.
  Stop from the printer's own buttons was not affected - they are not read during that
  lift.
- **The same after Resume.** A dashboard Stop pressed while the plate travelled back
  down stopped the print, but once the plate arrived the printer screen redrew live
  Stop and Pause buttons next to "Canceling...". They now stay grey to the end.
- **After a print resumed from a power cut, the plate is no longer raised at the end.**
  After such a resume the plate's height is only an estimate, and the lift to the top
  could drive the plate into the top of its travel. The printer now leaves the plate
  where it is and says "Raise the plate" - lift it with the manual lift. A pause in such
  a print also lifts the plate no higher than 62 mm (instead of 68 mm), to leave room
  for the small height error.
- **"Lift plate only" after a power cut stops short of the top, and can be stopped.** That
  lift runs on an estimated height, and the Z axis has only 3 mm of travel above its
  68 mm limit (measured), so it now stops 6 mm lower. The screen says "Watch it - BACK
  stops", and BACK does stop the move.
- **A power cut during a long plate move no longer offers a risky resume.** While the
  plate rises into a pause, travels back down after Resume, or rises at the end of a
  print, its real height does not match the one saved for resuming, and resuming could
  press the part into the screen or drive the plate into the top. The saved point is
  now dropped before those moves and written again when the plate stops, so a cut
  there simply boots normally.

## [0.17.0] - 2026-09-11 (beta)

### Added

- **Slice an STL in the browser** (plan SL-params, SL-mod). The printer now brings
  its own slicer: open the dashboard, pick an STL, and the model is oriented,
  supported, sliced and sent to the card - no PrusaSlicer, no ChiTuBox, no desktop
  computer at all. A phone is enough, and so is a printer with no internet, because
  the module lives on the SD card.
  - `Choose STL` -> orientation (**Fast fit**; **Optimal fit**, which searches for
    the rotation needing the fewest supports, the way PrusaSlicer does; **Lay flat**,
    **Flip over**, **Tilt 90 deg**, **Rotate 90 deg**) -> **Supports** and
    **Strength** -> **Slice** -> **Send to printer**.
  - Six controls sit under those buttons - Supports, Strength, Placement, Tip, Raft
    and Smoothing - plus **Reset**. The raft is counted in **layers**, not millimetres:
    the file is always sliced at 0.05 mm, and the printer decides how many of those
    images it actually exposes, so the same raft setting is a different number of
    millimetres at a different layer height. The default is **3 layers**, and the
    choice is 2, 3 or 6 - a one-layer raft was dropped because the pad does not bond
    to the part at all. Measured on this printer: a printed pad comes out about
    0.15 mm thicker than asked, so the 3-layer default lands on the ~0.3 mm that
    PrusaSlicer's plate gives, and it lifts off with a spatula without force.
  - The engine is PrusaSlicer's own **libslic3r**, unmodified, compiled to
    WebAssembly and used under **AGPL-3.0** - so the geometry is theirs, not an
    approximation of it.

- **Named resin profiles** (plan 0-16). A profile is the whole print recipe for
  one resin: base and regular exposure, base and transition layers, all four
  lift settings, the resin's density and its weighing calibration. Switching
  resin is one press instead of ten fields, and a value that took an exposure
  test to find can no longer be lost to a stray edit.
  - Four profiles are **built into the firmware** - `Fast fine`, `Fast draft`,
    `Slow fine`, `Slow draft` - two resins at both layer heights, so the picker is
    never empty: no SD card, no network, after a factory reset. The Fast pair
    carries the values measured on this printer (18 s / 8.0 s, density 1.157);
    the Slow pair is the factory set. The names say the LAYER: *fine* is 0.05 mm,
    *draft* is 0.10 mm, and the base-layer COUNT differs between them so that the
    printed base is 0.20 mm either way. The exposure is the same at both heights
    per the resins' own sheets; it has not been measured here at 0.10 mm.
    ⚠️ A profile of your own named `fast-draft` or `slow-fine` on the card becomes
    an overlay of the built-in with that slug: it keeps your values but shows the
    built-in's name, and “Reset to factory” deletes it. Rename yours first.
  - Editing a built-in writes an **overlay file** on the card that shadows the
    flash values; "Reset to factory" deletes it. Everything else lives in
    `/resin/*.json` - installed from the gh-pages library or saved by hand.
  - **Layer height is part of the profile**, because exposure without it is only
    half a number: 0.05 mm needs less light than 0.10 mm. Two profiles for one
    resin is the normal case, exactly like a slicer's material x layer-height
    rows. VAT size, the low-resin levels and the pause lift stay outside - those
    describe the printer, not the resin.
  - Picked from the **main dashboard view**, next to how much resin is left -
    which resin is in the vat is state, not a setting. The same row in Settings
    opens the recipe underneath it. Switching asks first if the values on screen
    have not been saved yet.
  - Printer screen: Advanced → Resin → **Resin profile** cycles and applies.
    Creating, renaming and deleting stay in the dashboard - there is no keyboard
    at the printer.
- **Resin left, by weight**. Enter the empty vat's weight once, then weigh the
  vat and the printer works out the millilitres left, instead of assuming a full
  vat from the marker.
- **Per-model print time in the SD list** (plan EST-model), recomputed from the
  resin profile in force - switch profile and every row updates.

- **Model preview, rebuilt as a real 3D view** (plan #93, PV-native, PV-slices,
  PV-stage). It used to draw 36 slices stacked like pancakes, which made anything
  detailed unreadable. Now the same slices become a smooth surface drawn on the
  GPU by three.js - served from the SD card, and failing that from our own pages,
  never from a stranger's CDN. The view takes the printer's native 320x240 masks
  instead of shrinking them to 80x60, and every layer of the model instead of 72
  of them, so what is on screen is measured data rather than interpolation.
  The window grows to the full width of a desktop, a slider cuts the model at any
  height, and the heavy build runs in ~30 ms slices so the browser never offers to
  close the page.
- **The growing print is visible in every browser** (plan P-live), not only in the
  window that happened to open Preview before the print started. A phone picked up
  mid-print now shows the model as it is being built, with the unprinted part left
  as a ghost.
- **Exposure in tenths of a second** (plan 0-3). Whole seconds in a single EEPROM
  byte flattened the short times that fast resins need; the Base minimum also comes
  down from 10 s to 5 s.
- **Adjustable pause lift height** (20-40 mm, default 20). Testing a new resin means
  looking at the plate mid-print, and 20 mm is not always enough room.
- **The printer says when a file is being sent to it.** While it receives, the ESP32
  answers no status polls at all, so a second device used to blink "idle" between two
  uploads. Now one calm line stands there and turns into "Unpacking" with a real
  count, on the printer's screen and in every dashboard (plan RX-say, RX-listen,
  SD-prog).
- **The slicer module lives on the SD card** (plan SL-mod), so a printer with no
  internet can still slice. The printer downloads the files once, compares each one
  against a checksum fetched from our pages, and accepts only matching bytes - this
  is the one place in the whole firmware where a TLS certificate is verified.
- **Marking a defect on the model** (plan MARK-bug). A tap leaves a mark with
  millimetres and a layer number, a drag marks a zone. The report attaches the slicer
  version, the dashboard's checksum, the firmware build and a 3D frame by itself, and
  arrives in the feedback box already tagged as a bug - so a complaint carries the
  facts needed to reproduce it.
- **A push message when power comes back** (plan PR-notify). An interruption used to
  be announced only on the printer's own screen; away from the machine, you learned
  about it when you came back.
- **Sub-millimetre resume** (plan 1-38b). A cut during the plate's motion used to
  resume from the pre-lift position, which could leave the rest of the print up to a
  lift-distance too high. Checkpoints now record mid-motion, with a Balanced/Precise
  toggle for how often they are written.
- **Crash telemetry** (plan CT). The reset reason was already shown on the About
  screen; it now travels with the anonymous ping, so it is possible to see how many
  printers fall over and why, instead of hearing about it one report at a time.
- **The printer says whether the last automatic message actually arrived**
  (GitHub #88). Sending returned success or failure with a reason, and the common
  path threw both away, so a broken Telegram token looked exactly like a quiet print.
  The delivery result and its reason are now kept and shown in the dashboard. The row
  names it the last *automatic* message on purpose: "Send test" takes a different
  path, and "the test works but printing sends nothing" is a diagnosis worth keeping.
- **Two-step low-resin handling** (GitHub #40): a heads-up before the stop, on the
  phone and in the dashboard, and paused or cancelled messages that carry the layer
  and the time elapsed instead of a bare word.
- **The low-resin stop can now be set to a level that works, and it is on by
  default.** The VAT is 42 x 52 mm inside, so a millimetre of resin is about 2.2 ml
  and a full 15 ml VAT is under 7 mm deep. Poured resin stops covering the whole
  floor at about 4 ml, and it clings to the walls, so the middle can open a dry
  patch a little above that. Below that level nothing prints, whatever the shape.
  The stop level used to be locked to 1-3 ml, so its highest setting was 1.4 mm -
  under the floor: the setting could not be made to work in any of its positions,
  and a print stopped forming layers without ever tripping it. It is now **3-8 ml,
  default 4**, the warning is **5-8 ml, default 5**, and the mid-print pause is
  **on** rather than opt-in, because carrying on below the floor prints nothing.
  Levels of 1 or 2 ml carried over from an earlier version are lifted to 4 on the
  first boot; a restored backup and **Back to Default** land on the same values.
  Worth knowing when planning a print: roughly 4 ml of every filling is there to be
  stood in, not printed with, so a 15 ml VAT gives about 11 ml of printing.
- **A resin pause is left by a full refill, not by pressing Resume.** When the printer
  stopped for low resin, Resume simply carried on: the level was not reset, nothing
  asked about it, and the low-resin stop stayed disarmed for the rest of the print.
  Now the dashboard's Resume stays grey and the printer answers
  "only Stop available, please refill" until the VAT is marked full; the orange
  **Set VAT full** button is the way on. On the printer's own screen the resume box
  asks **VAT filled full?** and Yes marks the refill before resuming, so a printer
  used without the dashboard is not left with Stop as the only way out. There is
  deliberately no "carry on without refilling": that means trusting the estimate,
  and refilling costs nothing - unused resin goes back into the bottle. A new
  `refillPending` field in `/api/status` says when this is the case.
- **One refill question everywhere, and a button named for what it does.** The same
  question was worded four ways; it is now **VAT filled full?** with No and Yes, on
  the dashboard and on the printer, before a print and in the resin pause. "VAT
  refilled" became **Set VAT full** on the dashboard and in the Advanced menu - it
  sets the level to a full VAT and measures nothing, so the word *full* has to be
  there. It also works while printing now, behind its confirm. While the plate lifts
  into a pause, the printer's title band says **Resin low...** or **Pausing...**
  instead of staying blank for the whole lift.
- **TinyStatus has a home in the README.** The Wear OS watch app lives in its own
  repository ([slibbinas/TinyStatus](https://github.com/slibbinas/TinyStatus)); the
  README says what it shows, what firmware it needs and what its polling costs the
  printer, and `docs/api.md` lists it under "Known consumers".
- **Everyday dashboard work**: the newest model on top of the SD list (it is a work
  queue, not an archive); Start and Delete appearing under the mouse on a desktop, so
  a row can be printed without paying for a preview; one SD footer line instead of
  two; buttons that visibly accept a press and show they are working; a 24-hour clock
  everywhere; lifetime and UV hours moved out of the live view into Statistics.

### Changed

- **The factory resin calibration is measured now, not assumed.** `Fast fine` and
  `Fast draft` ship with ×1.010 + 0.63 ml, fitted from two weighed prints
  (1.15 ml → 2.07 g and 3.34 ml → 4.63 g); it used to be ×1.092 + 0.39. The slope
  says the geometry was right all along - the whole correction is the ~0.6 ml of
  film left on the plate after every print. The published `sunlu-tough` library
  profile carries the same numbers, so "resin left" changes for everyone after
  the update.
- **"Reset to factory" and "Delete" say what they take with them.** Both remove
  the weighed prints stored in the same profile file; the confirmation now counts
  them, and the list refreshes as soon as a weighing is entered, so the warning
  cannot stay silent exactly when it matters.
- **Writes are accepted only from the printer's own dashboard** (GitHub #95). Any
  request that changes something must come with a matching Origin or the
  `X-TinyMaker: 1` header, so a page open in another tab cannot drive the printer.
  PrusaSlicer's upload path and the machine API are exempt by design; the rule is
  written up in [docs/api.md](docs/api.md).
- **About 60 KB of flash reclaimed** (plan F-opt), most of it a 576-case timing
  switch turned into a PROGMEM table, with identical behaviour. Done early on
  purpose: every feature after it had room to land.
- **Checkpoints are written once per layer instead of twice** (plan 1-38), which is
  half the SD wear for the same power-loss guarantee. Design by
  **Tanner Steorts ([@Tann2019](https://github.com/Tann2019))**.
- **A dry run no longer lifts the plate to the ceiling** (plan DRY-lift). Nothing was
  printed, so there is nothing to lift away from; it rises to the pause lift height
  and stops.
- **One busy rule for the whole dashboard.** Controls used to be locked one at a
  time, so some stayed live while the printer was working. Locking is now decided as
  a table and applied everywhere at once, including the settings pane and the SD list.
- **Ten fewer voices in the message area.** Long operations used to announce every
  stage; a chain of steps is one message now, with a bar when there is a number and
  silence when the screen already shows it.
- **The dashboard restores the last preview only within the same printer session**
  (plan DASH-boot). After a reboot it opens empty instead of pulling yesterday's model
  off the card, but F5 during a print still brings the progress view straight back.

### Fixed
- **After a resin stop the printer's screen showed pause and resume at once** - the
  yellow pause bars and the green play triangle on top of each other. The bars are
  now wiped before the triangle is drawn.
- **Old models in the SD list kept a blank icon after a print** until the page was
  reloaded: a row whose icon request met the busy printer marked itself "no icon"
  for the life of the page. The marks are cleared when the print ends.
- **The SD list during a print is quiet and says why it may be empty.** A browser that
  never saved the list (a phone opened mid-print) showed nothing under the lock line; it
  now adds that this browser has not saved the SD list yet and the card cannot be read
  while printing. While the printer is busy, Prev and Next are greyed out like the rows,
  and every row shows the drawn mark: the rows used to ask the printer for their icons
  and paging repeated that, all served from inside the print loop, and rows with an icon
  saved in the browser made the locked list look random. The icons return when the print
  ends.
- **The SD card no longer hangs one row below the left column when a print starts.** The
  preview card is briefly taller at the start; the list was fitted to that and stayed too
  long for about 11 s after the card shrank back. The list now refits whenever any card in
  the left column changes size.
- **Touching the endstop is a homing, and the pause lift no longer dives.**
  Reaching the endstop now zeroes the height counter and the screen says
  **Plate is home**. Before this, a pause lift requested at or above the ceiling
  did `moveTo(ceiling)` - which drove the plate *down into the part* mid-print.
- **"Save config" silently switched dry run off**, so the next print cured with
  the UV LEDs on when a dry run had been intended.
- **The 3D view comes back when the print ends**, not when the layer counter
  happens to fill up.
- **A dashboard opened mid-print showed the active resin as "Fast (missing)"**,
  so a phone and a PC disagreed about what was in the vat: an empty profile list
  was read as "gone" before it had loaded at all.
- **Supports stay on screen while the model is on its way to the printer.**
  Pressing Send used to strip them from the 3D view for the whole upload and
  unpack (~40 s on an 800-layer model), leaving the part hanging in the air.
- **The slicer card stopped jumping.** The "Saved as …" line always keeps its
  place now (46 px → 1 px when a slice finishes), the module version left the card
  (it lives under Settings → Update), and the preview no longer flashes an empty
  "Tap a model" box between a finished send and the model opening by itself.
- **The delete dialog names the file** instead of "Delete this SD item?", and the
  Update card no longer promises "Picked versions still work" when the printer
  cannot reach GitHub.
- **Smaller dashboard fixes from the test rounds:** test models say how long they
  take; a profile whose file is gone says so instead of carrying stale values; a
  broken boot-animation download no longer takes the old one with it; both layer
  sliders are the same length and usable on a phone; a print started by someone
  else no longer looks like a dead printer; a disabled control says why; the
  "firmware updated" message stays long enough to be read; the status bar fits
  its frame and the final lift says what it does; and the layer number no longer
  swallows clicks or drags the slider with it.
- **The manual jog stops at the top instead of grinding into it.** Above
  `max_height` the ULN2003 quietly drops steps while the counter keeps counting,
  so the plate ended up lower than the screen claimed. It now stops at the
  ceiling and says **Plate is at the top** - which is what you see right after a
  print, since the finishing lift parks the plate there. The limit applies only
  once the printer has homed: without a homing the zero is wherever the carriage
  happened to stand, and a limit measured from it would mean nothing.

- **A print of zero layers could be started.** The guard before Start compares
  the layer count against the height it was counted with - but switching resin
  re-counted the model and re-stamped that height, which disarmed the guard, and
  the "no layers" check lived inside it. If the card misread during that
  re-count, the preview showed `Layers: 0` with Start still live, and the plate
  would go down and the job "finish" without a single exposure. Counting and
  refusing now travel together in one place.
- **Printing with no resin selected.** Deleting the active profile left the
  printer with no profile name but with the deleted profile's exposure still in
  EEPROM, and printing carried on with that ghost recipe. Worse, after a reboot
  the empty name was silently renamed to `Slow resin (factory)` without applying
  its values, so the machine claimed one recipe and ran another. Printing is now
  refused until a resin is picked, at the printer (a new screen, with a one-press
  way out) and in the dashboard (409, and the Start buttons lock themselves
  within one poll on every open dashboard).
- **Factory reset left half the resin state behind.** Only the `Slow` overlay was
  removed, so `Fast` came back with pre-reset edits; the empty vat weight also
  survived, although the confirmation promises the weighings go. The
  confirmation screen itself had lost a word mid-sentence and no longer warned
  about the reboot it performs.
- **One damaged `/resin/*.json` killed the printer's Resin profile button** for
  good: the failed profile did not become current, so the next press offered the
  same broken file again, with no message - and the dashboard hides such an
  entry, so the cause was invisible.
- **A long profile name broke the Advanced menu layout.** Our own published
  "Anycubic Water-Washable Clear" is 229 px on a 150 px row, and Arduino_GFX
  silently wraps, so it landed on the next entry. Clipped now, like every other
  variable-width text.
- **The resin library shipped two profiles that would over-expose.** Both
  Anycubic entries carried the factory 35 s / 14.0 s recipe with the layer height
  halved to 0.05 mm - the same energy on half the layer. They are 0.10 mm now,
  and still carry no `tested by` badge.
- Preview drew the printer's plan instead of the model, so switching to a
  0.05 mm profile cut a model in half on screen (plan PV-resin-bug); a single
  lost slice froze it at `Building the 3D view N/240` for good.
- Saving a profile *with values* onto the profile that is currently active wrote
  the file without applying it, so the printer named one recipe and ran another.
- A profile file missing some keys inherited those values from whatever resin
  happened to be loaded, so the same file described different recipes at
  different times.
- Switching resin at the printer did not schedule the Connect backup, although
  the same change from the dashboard did.
- A `buy` link read from a card was only checked for `https://`, not against the
  catalogue allowlist that the write path uses, so a prepared card could put an
  arbitrary link in the dashboard looking like a printer recommendation.
- Settings, backup restore, model deletion and print start now refuse with 409
  while a resume is waiting to be answered.
- The offline demo dashboard read no POST parameters at all: it expected a
  string body while the app sends `URLSearchParams`, so every simulated action
  silently lost its arguments.
- **Every print came out flat if the slicer's layer height was not 0.05 mm**
  (GitHub #63, plan LH-chk). The height inside the uploaded `config.ini` was thrown
  away during unpacking and 0.05 mm silently assumed. It is read now, and a mismatch
  is refused rather than printed - and after a later fix, it is found even when the
  config outgrew the first kilobyte the reader looked at.
- **The network-free build stopped compiling** (GitHub #113): `Import.ino` called
  `sdJobService()` outside `#if ENABLE_NETWORK`, so the original firmware could not be
  built from this fork. CI now builds the working branches too, because a session in
  the cloud cannot run PlatformIO at all and nothing else would catch it.
- **A printer that booted with no network came back as half a printer** until it was
  restarted once more.
- **A preview cut used to lie about what was inside**, an upload of our own was
  reported as somebody else's, and a cancelled upload kept saying it was uploading.

## [0.16.2] - 2026-08-03 (beta)

Beta fixes and polish on top of 0.16.0.

### Added
- **Power-loss resume on/off switch** (System → Advanced → Resin, and the
  dashboard's Settings). Off means the printer never writes a checkpoint and
  never offers to resume after an outage - it starts fresh, like the stock
  firmware. On by default.
- **Dashboard header cleanup.** The firmware version is now a small badge next
  to the TinyMaker name; it turns orange with an ↑ when a newer version is
  waiting, and tapping it jumps to the Update screen. The theme toggle moved to
  the top-right corner, and the build hash is shown in **Update** and **About**.
- **Manual FAQ additions** - SD card formatting (FAT32, ≤32 GB), washing &
  curing, cleaning the resin vat, a clear layer-height warning (slice at
  0.05 mm), and a power-supply note for reliable power-loss recovery.

### Fixed
- **Self-update was a dead end when WiFi was off at boot.** System → Update now
  brings WiFi up so you can still check for and install firmware.
- **Lifting the plate off a stuck print** (from the resume prompt) now clears
  the checkpoint *before* the lift, so a power dip mid-lift can't leave a stale
  resume prompt with an already-raised plate.

## [0.16.1] - 2026-07-28 (beta)

### Added
- **"Buy me a coffee" link** in the dashboard's About footer.

### Fixed
- Menu item info text looked shrunk after a boot animation played - the badge
  font is now restored so Maintenance / Settings / System read at full size.

## [0.16.0] - 2026-07-23 (beta)

The biggest release since WiFi landed: your printer survives a power cut, every
long operation tells you what it's doing on every open dashboard, and the
printer's own screen finally shows when it's in a test run or has an update
waiting. Ships first as a **beta** (Update → version picker); the automatic
self-update channel follows once early testers confirm it.

### Added
- **Power-loss resume.** If the power drops mid-print, the printer remembers the
  layer on the SD card and, on the next boot, offers to **pick the print back up
  from where it stopped** - no starting over. A third choice safely **lifts the
  plate** off a stuck print (up only, never into the vat). You can answer all of
  this **from the dashboard on your phone**, not just at the machine - a first
  for a resin printer in this class. Field-tested with real power cuts and a
  resin print. *(Checkpoint engine by **Tanner Steorts ([@Tann2019](https://github.com/Tann2019)), PR #11** - thank you.)*
- **Clear live feedback on Stop / Pause / Resume.** Instead of a easy-to-miss
  button label, one message with a live countdown ("Stopping - finishing the
  current layer · ~18s"), shown centred on every connected dashboard.
- **Background SD work.** Deleting a model or importing an upload no longer
  freezes the dashboard - the work runs in the background and every connected
  device sees what the printer is doing and when it finished.
- **Mid-print preview from any device.** Open the dashboard mid-print on a fresh
  phone and still see the model preview (served from a RAM snapshot). *(Reported
  by Simon Fell.)*
- **A print-aware screen saver** - dims the idle screen, gently drifts the
  printer name/IP (no burn-in), shows live progress while printing, on by default.
- **Reorganized menus** on the printer and dashboard - Advanced grouped
  (Network / Resin / Display), a new **Statistics** screen (print hours, UV time,
  boot info), Update kept visible with an "update available" badge.
- **On-screen status badges** - a **DR** chip when dry-run is on (the UV LED is
  disabled), a **NEW** chip when a firmware update is available, and a messenger
  bubble when notifications are enabled - all on the printer's own screen.
- **Release notes in the updater** - a link to what changed next to every version.
- **Model details in the status panel** (layers, time, resin) and a smoother 3D
  progress view.
- **A self-refreshing model list** - a model uploaded from one device shows up on
  every open dashboard, no reload needed.
- **"Why did it restart?" diagnostics** - after an unexpected reboot the printer
  records the reason (and the layer, if printing) and shows it in Statistics.
- **Feedback tickets** - the feedback form now gives you a reference number and a
  status link, and shows a "recently handled" list.

### Fixed
- **Fresher print-time and resin estimates** right after a settings change.
- **Mobile navigation** no longer overflows on narrow phones; steadier MQTT
  reconnects.
- **WiFi credentials are no longer wiped** when discarding a resume prompt (a
  held button was misread as the power-on reset gesture).
- A **security pass** over the HTTP surface (POST endpoints, file paths, gate
  consistency); boot-animation install restricted to trusted hosts.

## [0.15.8] - 2026-07-19

A readability fix for the light theme.

### Fixed
- **The boot-animation list is readable in light theme again.** The animation
  names and sizes were painted in a hardcoded near-white grey that vanished
  against the light theme's white card - the whole list looked disabled
  (reported by a contributor). They now use the theme's own text colours, so
  they read clearly in both light and dark.

## [0.15.7] - 2026-07-18

WiFi that comes back on its own, and a tidier main menu.

### Fixed
- **The printer rejoins WiFi after a dropout.** Until now the firmware only
  connected at boot, so if the router dropped the link mid-use the printer
  stayed offline until a reboot - and the only recovery some users found was
  re-entering the WiFi password (the credentials were never actually lost). It
  now auto-reconnects in the background, with an idle watchdog that also
  re-announces `tinymaker.local` after a reconnect. It runs entirely off the
  print path, so exposure timing is untouched. (Reported via the feedback form.)

### Changed
- **Main-menu icons are centered and the row sits a touch lower.** Three of the
  four icons hugged the top of their boxes; they now sit centered like the gear,
  and the whole menu drops 2 px so the WiFi/Connect badge no longer crowds the
  highlighted box frame.

## [0.15.6] - 2026-07-20

Two small screens that matter at the worst moments.

### Fixed
- **The leveling screen now leads with safety.** Before homing, the warning
  reads *"Plate must be EMPTY. Homing goes DOWN."* - because leveling drives
  the plate toward the film, and a user recovering from a power outage lands
  on that screen in a panic (a real field incident prompted this). The manual
  gets a power-outage section too: raise the plate with *Move Build Plate*,
  never re-level with a print still attached.
- **Boot animations no longer pretend to load forever during a print.** The
  list said "Loading animations…" with a busy error below it; now it says
  plainly that animations live on the SD card and are locked while printing -
  and the list reloads by itself the moment the print ends.

## [0.15.5] - 2026-07-16

A screen-feedback patch: every long operation now shows live progress, and
nothing repaints more pixels than it changes.

### Fixed
- **The unpacking screen no longer flickers.** Extracting layers repainted the
  whole LCD every 20 layers; it now paints once and only grows a progress bar
  and updates the layer counter in place. The firmware-flashing screen never
  flickered for exactly this reason - now every progress screen works that way.
- **Real progress bars where a "wrapping" bar used to loop.** Model upload and
  boot-animation download showed a bar that swept and started over because the
  total size was "unknown" - it was in fact available (the upload's
  Content-Length; the animation's exact size from its own TMB header). Both now
  fill once, left to right. Flashing firmware from the dashboard gains a real
  bar too.
- **Deleting a big model from the dashboard no longer looks like a crash.**
  The printer's screen showed nothing while hundreds of layer files were being
  removed (tens of seconds, buttons unresponsive by design), and the
  dashboard's "deleting…" message vanished after 5 seconds with the model
  still listed. The LCD now shows the same *Deleting* progress screen the
  printer's own menu shows, and the dashboard message stays up until the
  printer confirms.

## [0.15.0 – 0.15.4] - 2026-07-15 / 2026-07-16

One beta wave, promoted to stable as 0.15.4 on 2026-07-16 (0.15.1–0.15.4 were
fix-ups of the 0.15.0 beta found during live testing).

### Added
- **Feedback link** - the dashboard header links a 30-second feedback form
  (firmware version attached automatically), so impressions and problems can
  land with the maintainer without a GitHub or Facebook account.
- **Always-on Model preview card** - the dashboard's 3D card no longer hides:
  idle shows a pick-a-model hint, the last previewed model is remembered and
  restored from the saved preview after a page reload, and a print started on
  the printer itself replaces a stale preview with a note instead of showing
  the wrong model. The SD list marks which row the preview came from - an
  accent rail and an *In preview* chip on the model you are looking at.
- **Home-screen app (PWA manifest)** - *Add to Home screen* now pins the
  dashboard with the project icon; on iPhone it opens fullscreen like an app.
- **WhatsApp and Discord notifications** - same three messages as Telegram
  (finished / low-resin pause / canceled): WhatsApp through the free CallMeBot
  gateway (one-time activation, inline help), Discord through a channel
  webhook (no bot needed). Settings has one *Phone notifications* choice:
  Off / Telegram / WhatsApp / Discord. **Both are shipped untested** - they
  ride on your own CallMeBot key or channel webhook, so the only test that
  proves anything is yours. Reports are very welcome, working or not.
- **Exposure undo** - when the exposure test (or a config save) replaces your
  Regular exposure, the old value is remembered and an *Undo (Xs)* link
  appears next to the field.
- **The 3D preview draws a surface instead of a fog of dots.** The printed part
  used to be a flat orange blob - harder to read than the unprinted ghost next
  to it. Every voxel was drawn, including the 86% buried inside, and the light
  was a gradient over the grid, so a flat top and a vertical wall came out the
  same colour and the shape disappeared. Only the faces the camera can see are
  drawn now, as the quads they are, shaded from a real surface normal - blocky
  geometry that reads as round, because the eye takes curvature from light.
- **A liveness dot next to State while printing** - green means the printer
  answered within the last few seconds; amber with *syncing* means it is
  mid-move and will answer at its next network window. Mid-print pauses stop
  reading as "the page hung", and the *Getting started* first-print step now
  explains the same thing up front.
- **Phase countdown** - the status card counts the current phase down next to
  its name: *Curing · 9s*, *Lifting · 4s*. Curing is exact; lifting and
  dropping use the previous layer's measured duration, so the first layer
  shows no number. The ride to the top after Stop or a finished print counts
  down the same way (*Canceling · 25s*) - that wait finally has a number.
- **The dashboard answers mid-print** - refreshing (or first opening) the page
  used to stall until the printer's next between-phase window, up to a full
  base exposure (~35 s). HTTP is now served during the exposure, during homing
  and during the final lift after Stop or a finished print - only the peel
  moves stay silent, where a service pause could mark the part. The UV LED is
  switched off by a hardware one-shot timer at the exact
  deadline, so serving a page can never lengthen an exposure - that timer also
  removes a small overrun that button presses have caused since the original
  firmware.
- The dashboard header links the project site, **tinymakerwifi.com**.
- **Light theme** - the dashboard gets a light/dark toggle (the crescent next
  to *Manual*); your choice sticks per browser. Same orange, no flash on load.
- **Branded WiFi setup** - the `TinyMaker-Setup` portal now shows the project
  logo, firmware version and where to find the manual, styled to match the
  dashboard.
- **Getting started guide** - a dismissible first-steps checklist on the
  dashboard (WiFi → slicer → first model → first print → exposure →
  integrations); the printer ticks steps off by itself where it can. Small
  **?** marks next to tricky settings (layer height, resin tracking, web
  control, backup) open short explanations.
- **Exposure test result entry** - after the test strip, the printer asks
  *"Best bar (count dots)?"*: cycle to the number of dots on the crispest bar
  and it sets *Regular exposure* itself - no manual Settings trip. Two extra
  positions shift the whole ladder shorter/longer for a re-run when no bar
  was right.
- **Install confirmation on the printer** - the on-device self-update now asks
  *"Install update?"* (with versions) before flashing, so a stray OK on the
  Update screen can't start it.
- **Anonymous usage ping** - once per firmware version (the first boot after a
  flash) the printer sends a hash of its factory MAC, the firmware version and
  the lifetime print hours, so we know how many printers are out there and
  which versions they run. Nothing else is sent, ever; switch it off in
  Settings (*Anonymous usage ping*).
- **Project logo** - the dashboard favicon is now the layer-stack + WiFi mark,
  and the Update tab shows a community counter (*N printers running
  TinyMakerWifi*) fed by the anonymous ping.
- **Web flasher** - the easiest first-time install ever:
  [connect.tinymakerwifi.com/flash.php](https://connect.tinymakerwifi.com/flash.php)
  flashes the latest release straight from a Chrome/Edge browser over USB -
  nothing to download or install. *(contributed by [@Briadark](https://github.com/Briadark))*
- **Safe model imports** - uploads unpack into a temporary folder and only
  replace the old model once the new one has unpacked successfully; uploading
  a name that already exists asks *Replace / Rename / Cancel* (a PrusaSlicer
  re-upload just replaces, as before). Each model now carries a `model.json`
  with its metadata, so the resin estimate and details survive without
  re-scanning, and previews are cached on the SD card.
  *(contributed by [@Briadark](https://github.com/Briadark))*
- **Connect auto-backup & recovery** - an *Auto backup settings to Connect*
  checkbox (Settings → Network → TinyMaker Connect, with a confirmation on
  toggle) keeps a settings backup on the Connect server after changes and
  prints; a per-printer **recovery code** (Retrieve / Copy buttons) lets you
  reclaim your Connect profile after a reset. The Connect tab itself is now
  **loaded from the Connect server** (only once registered), so it can grow
  without costing printer flash. *(contributed by [@Briadark](https://github.com/Briadark))*
- **Boot animations rework** - picking an animation is now staged and applied
  with *Save config*; a **Show** button plays any installed animation on the
  printer's screen (idle only); a **Default library** hosted on the project's
  GitHub Pages offers one-click **Install**; and a **Shuffle** option plays a
  random installed animation each boot *(Shuffle by [@Briadark](https://github.com/Briadark);
  boot animations base by [@Tann2019](https://github.com/Tann2019))*.
  Installing no longer auto-selects. Recommended animation length is 2–4 s -
  the firmware hard-caps playback at 250 frames / 10 s, and Back skips it.
- **Model preview in the dashboard** - every SD model row now has
  *Preview | Start | Delete*; Preview renders the model into the dashboard's
  **Model preview** card (the former *Print progress 3D* card) with a live %
  progress bar, a compact info line (layers · height · time · resin) and a
  *Share model* button. Starting a print takes the card over automatically.
- **Quick resin estimate** - the preview render now yields a free `~X ml
  (quick)` estimate when the exact value isn't known yet; clicking the `~`
  value runs the exact printer-side scan (confirmed first - it decodes every
  layer and takes about a minute per 100 layers).
- The manual gained an advanced section on deriving your resin's **working
  curve (Jacobs)** from the test strip with calipers.

### Changed
- **The SD manager is ordered by how often each part is used** - the model
  list first, upload as a small one-click button in the card's header (pick a
  file and it uploads; it turns orange only when the card has no models, when
  it really is the call to action), and storage as a slim footer that turns
  amber past 85%. The action column lines up from the header down, model rows
  dropped the *Model folder* subtitle, and on phones Preview/Start scroll the
  preview card into view - it used to render above the fold where nothing
  seemed to happen.
- **The Update tab installs from one row** - version picker, *Install
  selected* and the file fallback side by side. Flashing a downloaded
  firmware.bin is one click into a confirm that names the file and its size,
  and the file path no longer disappears when GitHub is unreachable - it is
  the offline lifeline, after all.
- **The status card reads in pairs that belong together** - condition
  (State · SD card), network (WiFi · IP), the two lifetime counters, resin;
  while printing, resin sits next to resin and the two clocks share a row,
  with Layer closing the card. Phones keep the two columns now instead of
  stacking everything single-file.
- The screen-sleep setting is called **Idle screen timeout** - it only ever
  applied when idle, but the old name read as if the screen should sleep
  mid-print too.
- **Settings got second-level tabs** - *Print / Network / Notifications /
  Boot animation / Backup*, one section at a time, each with its own *Save
  config* (saving from any section preserves the others' values). The Backup
  section keeps only actions; the Connect auto-backup switch lives under
  Network. The Connect tab's sub-tabs share the same underline style, with the
  registration status shown at the bottom.
- **WiFi boot** - while connecting, the printer shows animated signal bars
  (they turn green on success) instead of a progress bar; the separate
  *"WiFi connected / IP"* screen is gone, **except** after first-time portal
  setup, where the IP is still shown. The IP is always available under
  System → WiFi Info.
- The old separate model-details view is no longer reachable from the
  dashboard - the Model preview card replaces it (Connect deep-links still
  use it).

### Fixed
- **Stop during homing brings the plate back.** Cancelling a print while it was
  still homing left the plate hanging wherever it stood. It now retraces the
  descent - up, and only as far as it came down. (It cannot lift to the top
  there: mid-homing the endstop hasn't been reached, so the true height is
  unknown, and lifting blind would drive into the top. Retracing needs no
  reference at all.)
- **The SD card list survives a reload mid-print** - a page opened or reloaded
  while printing showed an empty card, because a fresh tab has nothing cached
  and the printer won't read the SD while it feeds layers. The list is kept in
  the browser now; it can't go stale, since the card is locked for the whole
  print anyway.
- **The upload button is a single gate.** Two places decided whether it was
  enabled - one watching web control, the other the printer - and neither saw
  the whole picture, which could leave an enabled button in front of a disabled
  file picker: a control that silently did nothing.
- **"Printer busy" errors say when they pass** - every action blocked during
  a print now answers *"The printer is busy printing - this unlocks when the
  print ends."* instead of the bare server text.
- **Starting a print no longer flashes a false "timeout".** The printer's
  answer can miss the browser's window when the firmware sits in a network
  timeout, but the command has already landed - the dashboard now confirms
  via the status and says *Print started* instead of crying failure over a
  start that worked.
- **Homing no longer freezes the motor and the dashboard for seconds at a
  time.** The homing loop serviced the full network stack - including MQTT
  and Connect sync, whose timeouts run up to ~8 s. It serves plain HTTP now.
- **A garbled printer answer can no longer blank the SD manager** *(reported
  through the feedback form by a beta tester - thank you!)*: the file-list
  reply could go out truncated right after a heavy upload, and the dashboard
  rendered it as an empty list until a page refresh. Fixed on three layers,
  and the error state now offers a Retry link.
- **Stop and Pause are the same size** - Stop had borrowed the small SD-row
  delete style along with its red.
- **A dashboard opened mid-print no longer shows the idle "pick a model"
  card** - and a temporary "printer busy" answer no longer erases the
  remembered preview, so the model comes back on its own once the print
  finishes.
- **A print started from the web wakes the printer's screen.** If the screen
  had blanked on its timeout, a dashboard-started print used to run entirely
  on a dark display - with the buttons still acting, invisibly.
- **A cut-off boot-animation download is no longer installed as if it worked.**
  If the connection dropped or stalled mid-download, the printer kept the
  partial file, wrote its metadata and reported success - the animation then
  simply stopped wherever the bytes ran out. On a slow link a 1.4 MB animation
  arrived as 538 KB and still looked installed. The file's own header states
  how big it should be, so a short download is now deleted and reported
  instead. *(found by [@Briadark](https://github.com/Briadark))*
- **Boot animations play at the speed they were drawn.** The player slept a
  full frame delay *on top of* the time it takes to read each frame off the SD
  card, so everything ran about 1.8× slow - the *Malfunction* animation dragged
  on for 6.3 s. It now paces frames to the `fps` the animation was authored at.
  *Malfunction* was also the longest in the library by a wide margin, so it was
  re-timed to 24 fps: 6.3 s → 2.3 s. Install it again from the Connect tab to
  get the shorter version; the animation itself is unchanged.
- **The exposure test strip works at low exposures again.** With *Regular
  exposure* at 1 s, all eight bars rounded to the same whole second - the strip
  burned eight identical bars that blanked at once and measured nothing, which
  is exactly where fast resins live. Below ~5 s the ladder now steps 1 s at a
  time instead of by percentage: eight distinct bars, each one a value you can
  actually set. Above that, the ladder is unchanged.
- **The printer no longer freezes for seconds at a time when GitHub is slow.**
  A failed firmware-version check wasn't remembered, so every dashboard
  request for the update state re-ran the blocking check - the web UI and the
  screen stalled with it. Failures are now cached for a minute, successes for
  five as before.
- The **print-canceled phone notification** is sent the moment the cancel is
  final (with the run time), instead of after the final lift finishes - it
  used to arrive up to a minute late.
- **Connect sync retries back off exponentially** (30 s → … → 30 min) and give
  up after repeated failures - an unreachable Connect server no longer
  freezes the printer for 8 s every 30 s indefinitely.
- Model uploads now **fail with a clear message after 10 minutes** of printer
  silence instead of waiting forever.
- Model uploads no longer look stuck at *"Uploading 100%"* while the printer
  unpacks the archive - the indicator now says *Unpacking on the printer…*
  with a running timer (applies to the SD manager upload and Connect Import
  alike).
- Boot-animation **Show** now wakes a screen blanked by the UI timeout -
  it used to play onto a switched-off display, which looked like nothing
  happened.
- **mDNS stability** - WiFi modem sleep is disabled, so `tinymaker.local`
  resolves reliably instead of timing out when the printer naps.
- Dashboard requests get a single fresh-connection retry, the status toast
  only appears after repeated failures (not one hiccup), and settings forms
  refuse to post until the settings have actually loaded - no more
  accidentally saving a blank form over your config.

## [0.14.3] - 2026-07-13

### Added
- **Telegram notifications** - the printer messages you when a print
  **finishes** (with time + resin used), **pauses for low resin**, or is
  **canceled**. One On/Off switch, a bot token and a chat id, and a *Send test*
  button; inline setup steps (@BotFather / @userinfobot) right in the dashboard.
- **Restore from SD** button on the dashboard (enabled only when a backup file
  is present), and the **date of the SD backup** shown in Settings.
- **Downloadable boot animations** - a small on-device library of named
  animations you can pick on the printer or in the dashboard, and install
  straight from the community site. *(contributed by [@Tann2019](https://github.com/Tann2019))*
- **Build tag in the dashboard header** - experimental builds show their git
  commit next to the version (`Firmware 0.14.3 (abc1234)`), so you can tell
  exactly which build is flashed.
- **TinyMaker Connect (early preview)** - an opt-in link to the community
  model-sharing service being built by [@Briadark](https://github.com/Briadark).
  Off by default; when enabled in Settings, a Connect tab shows your shared-model
  activity. The service itself is still in testing - more when it opens up.

### Changed
- **Dashboard styling pass:** native browser confirm dialogs replaced with a
  modal that matches the printer UI; the status toast moved to a bolder,
  animated snackbar that appears next to your click; Settings split into
  *Print settings / Network & integrations / Backup & restore* cards; the
  Connect tab slimmed to just the model activity (registration details moved to
  the Settings Connect section); secret fields (Telegram, Connect) show only a
  masked *ends in XXXX* tail and are never echoed back.

### Fixed
- A page left open no longer serves a stale version after a reflash (the cache
  tag now includes the build), and the "Updating firmware" overlay clears
  within seconds instead of lingering after the printer is back.
- A homing abort/error no longer sends a "Print finished" notification.
- Blocking test/health calls (Telegram, Connect) are gated so they can't run
  mid-print; the Connect manager buttons and settings-backup were hardened
  (script-injection escaping, the Connect registration is now included in the
  backup).

## [0.14.2] - 2026-07-12

### Fixed
- Status messages (Config saved, Backup to SD, resets…) were invisible in the
  Settings and Update tabs - the toast lived in a hidden part of the page.
  Moved so feedback shows in every tab; most visibly, **Backup to SD** now
  confirms it worked.

## [0.14.1] - 2026-07-12

### Added / Changed
- **Exposure calibration test** improvements: each bar carries its number as
  **dots** (so a peeled strip stays identifiable), and the bar times are now
  **proportional** to your Regular exposure (40–160%), so the spread is
  meaningful for fast and slow resins alike.
- **WiFi signal bars** on the WiFi Info screen; light/dark **manual themes**.

### Fixed
- Running-time display no longer flickers between two formats each second.

## [0.14.0] - 2026-07-11

The last feature release before the pre-1.0.0 freeze.

### Added
- **Settings backup & restore** - one file holds every setting and the lifetime
  counters; keep it on the SD card and the printer offers to restore it on the
  first boot after a full USB reflash.
- **Boot update check** - shortly after WiFi connects the printer checks for new
  firmware and offers *Install / Later* on screen. *(contributed by [@Briadark](https://github.com/Briadark))*
- **Exposure calibration test**, **UV LED lifetime hours**, **print-finish ETA**
  (NTP), heap/uptime instrumentation for soak testing, and an illustrated
  [user manual](https://slibbinas.github.io/TinyMakerWifi/manual/).

### Credits
- The **initial web dashboard** and the **Advanced menu** (WiFi & Web-control
  switches) were contributed by **Brian Karmelk ([@Briadark](https://github.com/Briadark))**.

## Earlier (0.9.x – 0.13.x)

The WiFi stack, captive-portal setup, PrusaSlicer "Send to printer" (SL1 /
OctoPrint emulation), SD import, OTA self-update, the 3D model preview & live
print progress, resin estimation & VAT tracking, MQTT / Home Assistant, and the
read-only dashboard mode were built up across the 0.9–0.13 series. See the
[Releases page](https://github.com/slibbinas/TinyMakerWifi/releases) for details.

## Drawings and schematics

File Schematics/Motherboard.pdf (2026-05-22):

TYPE-C | ESP32 | CARD | FPC CONNECTOR

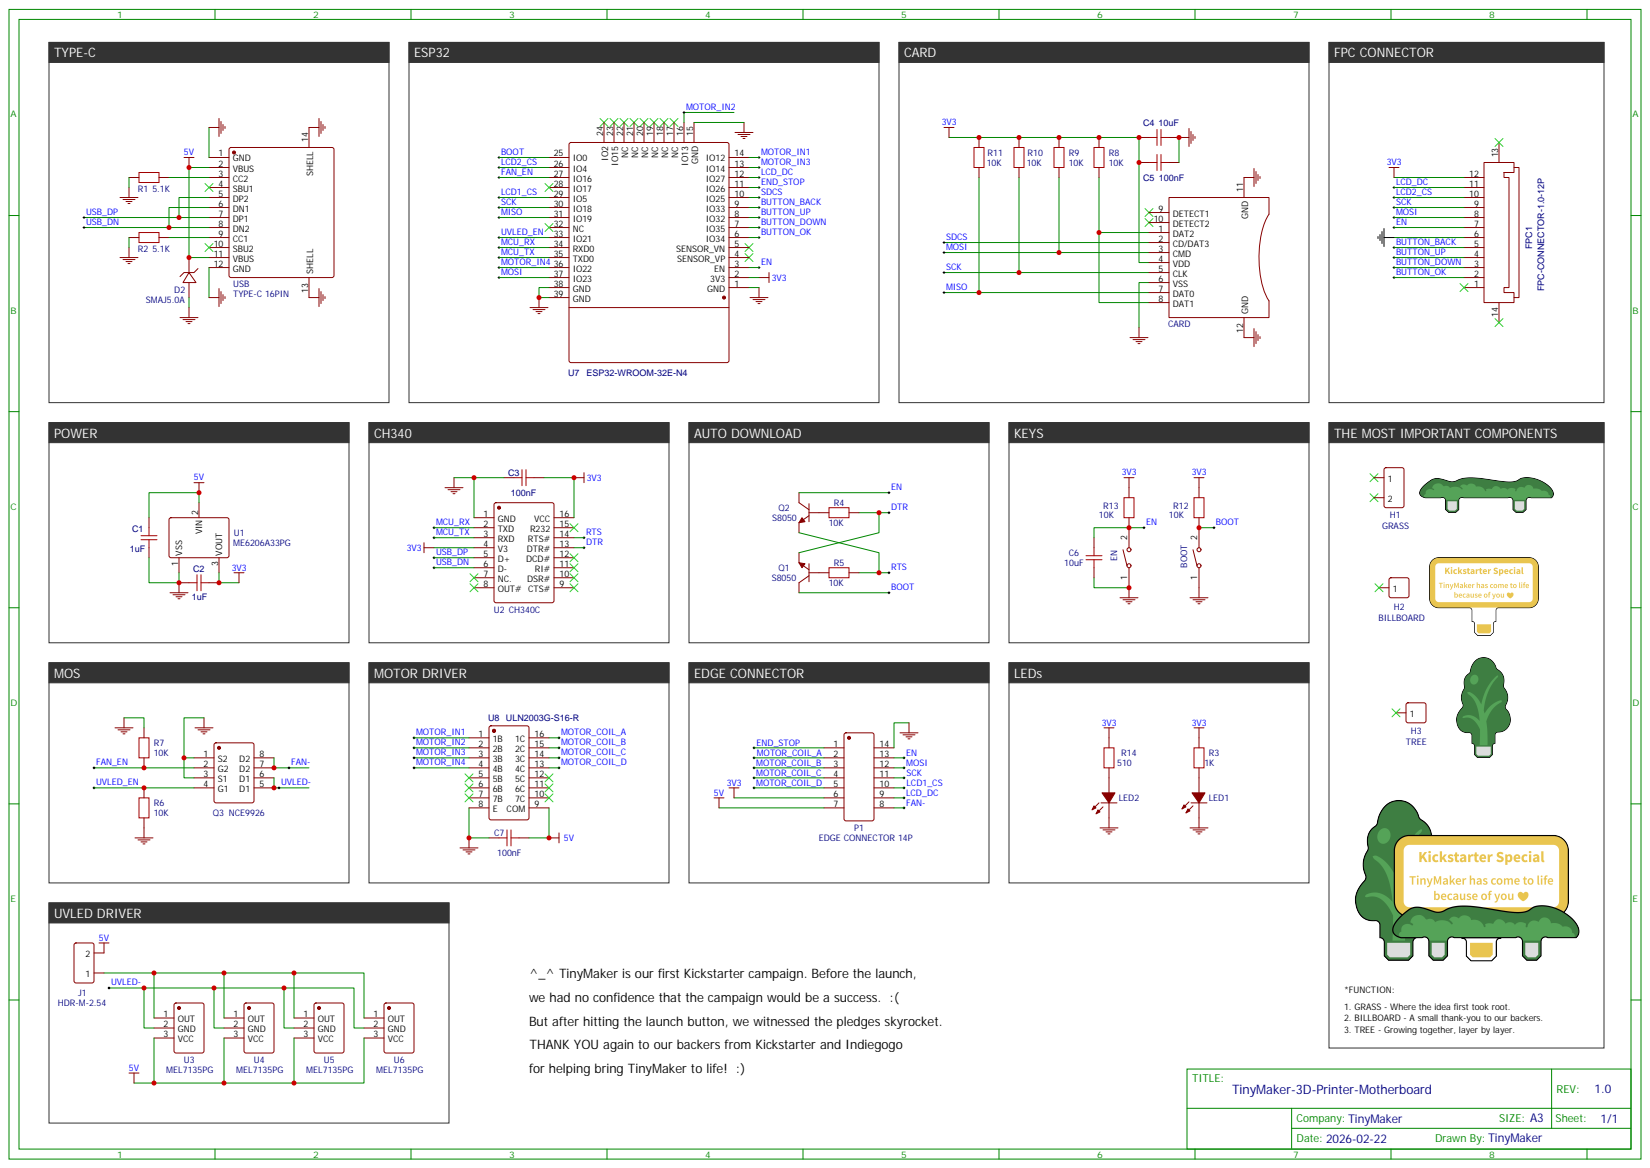
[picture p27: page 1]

GND 15 IO13 16 NC 17 NC 18 NC 19 NC 20 NC 21 NC 22 IO15 23 IO2 24

THE MOST IMPORTANT COMPONENTS

DSR# 10 RI# 11 DCD# 12 DTR# 13 RTS# 14 R232 15 VCC 16

^_^ TinyMaker is our first Kickstarter campaign. Before the launch,
we had no confidence that the campaign would be a success. :(
But after hitting the launch button, we witnessed the pledges skyrocket.
THANK YOU again to our backers from Kickstarter and Indiegogo
for helping bring TinyMaker to life! :)

*FUNCTION:
1. GRASS - Where the idea first took root.
2. BILLBOARD - A small thank-you to our backers.
3. TREE - Growing together, layer by layer.

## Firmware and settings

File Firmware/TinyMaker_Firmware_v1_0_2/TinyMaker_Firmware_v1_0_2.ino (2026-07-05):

/**
 * @file TinyMaker-Firmware-v1-0-2.ino
 * @author Tinymaker Team
 * @version 1.0.2
 * @date 2026-01-30
 * @brief Main firmware for Tinymaker MSLA 3D Printer.
 *
 * This file handles the entire print process, UI interaction, motor control, and UV exposure logic. 
 *
 * changes
 * - Added detailed comments (EN)
 * - Removed dead code
 * - Code organization and cleanup
 * - Corrected typo: "Maintenance" of Screen 2: Main Menu
 */

#include <SPI.h>
#include <EEPROM.h>              // For storing settings persistently
#include <AccelStepper.h>        // Stepper motor control library
#include <Arduino_GFX_Library.h> // Graphics library for driving displays
#include "FreeSans8pt7b.h"       // Custom font
#include <PNGdec.h>              // PNG decoder library for reading print layers
#include <SdFat.h>               // SD card file system library

// ===================================================================================
// Pin Definitions
// ===================================================================================

// Button Pins
// Used for UI navigation and control
const int buttonBack = 33; // Back button
const int buttonUp = 32;   // Up button
const int buttonDown = 35; // Down button
const int buttonOK = 34;   // OK/Select button

// Sensor & Actuator Pins
const int end_stop = 26; // Z-axis endstop switch (limit switch)
const int mot_en = 13;   // Motor Enable pin
const int mot_step = 12; // Motor Step pin
const int mot_dir = 14;  // Motor Direction pin
const int LED = 21;      // UV LED control pin
const int FAN = 16;      // Cooling fan control pin
const int SDCS = 25;     // SD Card Chip Select pin

// ULN2003 Motor Driver Pins
// These pins drive the stepper motor coils via ULN2003
#define IN1 12
#define IN2 13
#define IN3 14
#define IN4 22

// initialize the stepper library
AccelStepper stepper(AccelStepper::HALF4WIRE, IN1, IN3, IN2, IN4);

// ===================================================================================
// Display Configuration
// ===================================================================================

// Display 1: Masking LCD (UV masking)
// This screen displays the layer image
Arduino_DataBus *bus = new Arduino_ESP32SPI(27 /* DC */, 5 /* CS */, 18 /* SCK */, 23 /* MOSI */, 19 /* MISO */, VSPI /* spi_num */);
Arduino_GFX *gfx1 = new Arduino_ST7789(bus, -1 /* RST */, 1 /* rotation */, true /* IPS */);

// Display 2: UI LCD (User Interface)
// This screen shows the menu and status to the user
Arduino_DataBus *bus2 = new Arduino_ESP32SPI(27 /* DC */, 4 /* CS */, 18 /* SCK */, 23 /* MOSI */, 19 /* MISO */, VSPI /* spi_num */);
Arduino_GFX *gfx2 = new Arduino_ST7735(bus2, -1 /* RST */, 3 /* rotation */, true /* IPS */,80 /* width */, 160 /* height */, 26 /* col offset 1 */, 1 /* row offset 1 */, 26 /* col offset 2 */, 1 /* row offset 2 */);

// ===================================================================================
// Global Variables
// ===================================================================================

// Timing Calculation Variables
// Used to track print time and button press duration
int startTime;
int Duration;
int startTime2;
int Duration2;

// State Variables
int screen = 1;             // Current screen ID
int counter = 0;            // General purpose counter (e.g., used for folder navigation)
long Position_before_pause; // Z-axis position stored when pausing

// Estimation Variables
// Used to calculate object height ang remaining print time
float total_height; // Total height of the object to print
long estimated_seconds;
byte estimated_hours;
byte estimated_minutes;
float motor_updown_time;       // Time taken for one up and down cycle
float motor_updown_time_total; // Total time spent on motor movements

// UI Navigation Variables
int setting_item;              // Current selected item in settings menu
bool setting_item_updown = 1;  // Direction indicator for settings (1=up, 0=down)
bool printing_item_updown = 1; //1=up,0=down.

// Printing Flags
bool homing_canceled = false; // Flag: Homing process canceled
bool print_paused = false;    // Flag: Print is currently paused
bool print_canceled = false;  // Flag: Print process canceled

// Motion Parameters
float steps_mm = 1463;     // Steps per millimeter for Z-axis
int homing_Feedrate = 300; // Feedrate for homing
float max_height = 68;     // Maximum build height (mm)

// System State
int current_layer = 0; // Current layer being printed
int current_state = 0; // Current printing state
                       // (0=Homing, 1=Curing, 2=Lifting, 3=Dropping, 4=Canceling)
                       // (5=Pausing, 6=Paused, 7=Resuming, 8=Finish)

// Print Parameters (Loaded from EEPROM) 
float Layer_Height ;        // Layer thickness (mm)
long Base_Exposure ;        // Exposure time for base layers (s)
long Regular_Exposure ;     // Exposure time for normal layers (s)
byte Base_Layer ;           // Number of base layers
byte Transition_Layer ;     // Number of transition layers
byte Slow_Lift_Distance ;   // Distance for slow lift (mm)
byte Fast_Lift_Distance ;   // Distance for fast lift (mm)
int Slow_Lift_Feedrate ;    // Speed for slow lift (mm/min)
int Fast_Lift_Feedrate ;    // Speed for fast lift (mm/min)
int Drop_Back_Feedrate ;    // Speed for retract (mm/min)

// Default Manual Exposure Time
int manual_exposure = 35;

// Exposure calculation helper for transition layers
float Transition_Exposure ; 

// SD card instance
SdFat SD;

// File System Variables
char foldersel_long[101]; // Buffer for long folder names
String foldersel;         // Selected folder name (display version)
int layer_counter;        // Total number of layers
File root;                // Root directory object
String DirAndFile;        // Full path helper
String FileName;          // Current file name

// PNG Decoding
File myfile;
PNG png; // PNG decoder instance

// ===================================================================================
// Setup Function
// ===================================================================================
/**
 * @brief Setup Function
 * Initializes all hardware components, loads settings, and sets the initial state
 */
void setup() {  
  // -----------------------------------------------------------------------------------
  // Pin Configuration
  // -----------------------------------------------------------------------------------
  pinMode(buttonBack, INPUT);
  pinMode(buttonUp, INPUT);
  pinMode(buttonDown, INPUT);
  pinMode(buttonOK, INPUT);
  pinMode(end_stop, INPUT);
  pinMode(LED, OUTPUT);
  pinMode(FAN, OUTPUT);
  digitalWrite(LED, LOW); 
  digitalWrite(FAN, LOW);

  // -----------------------------------------------------------------------------------
  // Stepper Motor Configuration / 步进电机配置
  // -----------------------------------------------------------------------------------
  // Set maximum speed in steps per second
  // Higher values mean faster movement but less torque  
  stepper.setMaxSpeed(1200.0);
  
  // Set acceleration in steps per second^2. Controls how fast the motor ramps up to speed  
  stepper.setAcceleration(2500.0);
  
  // Disable motor outputs initially to save power and reduce heat when idle  
  stepper.disableOutputs();

  // -----------------------------------------------------------------------------------
  // SD Card Initialization / SD 卡初始化
  // -----------------------------------------------------------------------------------
  // Initialize SD card using the dedicated Chip Select pin and a safe SPI frequency (16MHz) 
  SD.begin(SDCS, SD_SCK_MHZ(16));
    
  // -----------------------------------------------------------------------------------
  // Displays Initialization / 显示屏初始化
  // -----------------------------------------------------------------------------------
  // Display 1: Masking LCD (UV masking)  
  gfx1->begin();
  gfx1->fillScreen(BLACK);  
  
  // Display 2: UI LCD (User Interface)
  gfx2->begin();
  gfx2->fillScreen(BLACK);
  
  // Display Welcome Screen
  screen0();

  // -----------------------------------------------------------------------------------
  // Settings Loading
  // -----------------------------------------------------------------------------------
  // Initialize EEPROM with 24 bytes of space to read stored parameters.  
  EEPROM.begin(24);

  // Read stored values from specific addresses.
  // Layer Height is stored multiplied by 100 to save as integer, so divide by 100.00 to restore float  
  Layer_Height = EEPROM.read(1) / 100.00;
  Base_Exposure = EEPROM.read(2);
  Regular_Exposure = EEPROM.read(3);
  Base_Layer = EEPROM.read(4);
  Transition_Layer = EEPROM.read(5);
  Slow_Lift_Distance = EEPROM.read(6);
  Fast_Lift_Distance = EEPROM.read(7);
  Slow_Lift_Feedrate = EEPROM.read(8);
  Fast_Lift_Feedrate = EEPROM.read(9);
  Drop_Back_Feedrate = EEPROM.read(10);
  
  delay(1000);
  screen1(); // jumps to Main Menu
}

// ===================================================================================
// Main Loop
// ===================================================================================
/**
 * @brief Main Loop
 * Handles button inputs and UI state transitions continuously.
 */
void loop() {  
  // -----------------------------------------------------------------------------------
  // Back Button Handling
  // Only triggers if the button is pressed (LOW)
  // -----------------------------------------------------------------------------------  
  if (digitalRead(buttonBack) == LOW) {
    switch (screen) {
      case 11:
      screen1();       
        break;
      case 111:
      screen11();
      counter --;
      folderDown(root);
        break;
      case 112:
      screen11();
      counter --;
      folderDown(root);
        break;      
      case 12:
      screen1(); 
        break;
      case 21:
      screen1(); 
      screen2();
        break;
      case 22:
      screen1(); 
      screen2();
        break;
      case 23:
      screen1(); 
      screen2();
        break;
      case 211:
      screen21(); 
        break;
      case 212:
      screen21(); 
        break;
      case 213:
      gfx2->fillRoundRect(2, 20, 156, 56, 3, BLACK); 
      gfx2->setTextColor(WHITE);
      gfx2->setCursor(46, 43);
      gfx2->print("Canceled");
      delay(600);
      gfx2->setTextColor(BLACK);
      gfx2->setCursor(46, 43);
      gfx2->print("Canceled");
      delay(600);
      gfx2->setTextColor(WHITE);
      gfx2->setCursor(46, 43);
      gfx2->print("Canceled");
      delay(600);
      gfx2->setTextColor(BLACK);
      gfx2->setCursor(46, 43);
      gfx2->print("Canceled");
      delay(600);
      gfx2->setTextColor(WHITE);
      gfx2->setCursor(46, 43);
      gfx2->print("Canceled");
      delay(600);
      screen21(); 
        break;
      case 221:
      screen21();
      screen22();
        break;
      case 222:
      screen21();
      screen22();      
        break;        
      case 223:
      screen21();
      screen22();      
        break; 
      case 2211:
      screen221();
        break;
      case 2221:
      screen221();
      screen222();      
        break;        
      case 2231:
      screen221();
      screen223();      
        break; 
      case 231:
      screen21();
      screen23();
        break;
      case 2311:
      screen21();
      screen23();
        break;
      case 31:
      screen1(); 
      screen3();
        break; 
      case 311:
      if(setting_item_updown == 1){
        setting_item ++;
        screen31UP();
      }
      if(setting_item_updown == 0){
        setting_item --;
        screen31DOWN();
      }
      delay(300);
        break; 
      case 3111:
      Layer_Height = EEPROM.read(1) / 100.00;
      Base_Exposure = EEPROM.read(2);
      Regular_Exposure = EEPROM.read(3);
      Base_Layer = EEPROM.read(4);
      Transition_Layer = EEPROM.read(5);
      Slow_Lift_Distance = EEPROM.read(6);
      Fast_Lift_Distance = EEPROM.read(7);
      Slow_Lift_Feedrate = EEPROM.read(8);
      Fast_Lift_Feedrate = EEPROM.read(9);
      Drop_Back_Feedrate = EEPROM.read(10);
      if(setting_item_updown == 1){
        setting_item ++;
        screen31UP();
      }
      if(setting_item_updown == 0){
        setting_item --;
        screen31DOWN();
      } 
        break;
    }
    delay(200);
  }

  // -----------------------------------------------------------------------------------
  // Up Button Handling
  // -----------------------------------------------------------------------------------  
  if (digitalRead(buttonUp) == LOW) {
    switch (screen) {
      case 2:
      screen1();    
        break;
      case 3:
      screen2();
        break;
      case 11:
      folderUp(root);
        break;
      case 22:
      screen21();
        break;
      case 23:
      screen22();
        break;
      case 222:
      screen221();
        break;
      case 223:
      screen222();
        break; 
      case 2211:
      manual_lift();
        break;
      case 2221:
      manual_lift();
        break;
      case 2231:
      manual_lift();
        break;      
      case 2311:
      screen2311increase();
        break;            
      case 31:
      screen31UP();
        break;
      case 311:
      screen3111increase();
        break;
      case 3111:
      screen3111increase();
        break;
    }
    delay(200);
  }  

  // -----------------------------------------------------------------------------------
  // Down Button Handling
  // -----------------------------------------------------------------------------------  
  if (digitalRead(buttonDown) == LOW) {
    switch (screen) {
      case 1:
      screen2();      
        break;
      case 2:
      screen3();
        break;
      case 11:
      folderDown(root);
        break;
      case 21:
      screen22();
        break;
      case 22:
      screen23();
        break;
      case 221:
      screen222();
        break;
      case 222:
      screen223();
        break;
      case 2211:
      manual_down();
        break;
      case 2221:
      manual_down();
        break;
      case 2231:
      manual_down();
        break;
      case 2311:
      screen2311decrease();
        break;                    
      case 31:
      screen31DOWN();
        break;
      case 311:
      screen3111decrease();
        break;
      case 3111:
      screen3111decrease();
        break;
    }
    delay(200);
  }  

  // -----------------------------------------------------------------------------------
  // OK Button Handling
  // -----------------------------------------------------------------------------------  
  if (digitalRead(buttonOK) == LOW) {
    switch (screen) {
      case 1:
      if (SD.begin(SDCS, SD_SCK_MHZ(16))){
        root = SD.open("/");
        screen11();
        counter = 0;
        folderDown(root);                        
      }
      else{
        screen12();
      }
        break;
      case 11: {
      gfx2->fillScreen(BLACK);
      gfx2->fillRoundRect(0, 0, 160, 80, 5, ORANGE);
      gfx2->fillRoundRect(2, 2, 156, 76, 3, BLACK); 
      gfx2->setFont(&FreeSans8pt7b);
      gfx2->setTextColor(WHITE);
      gfx2->setTextSize(1);
      gfx2->setCursor(22, 34);
      gfx2->print("Processing files");   
      gfx2->setCursor(34, 52);
      gfx2->print("Please wait...");
      delay(500); 
 
      layer_counter = 0;
      File entry;
      do {
        layer_counter += 100;
        FileName = foldersel_long;
        FileName += "/";
        FileName += layer_counter;
        FileName += ".png";
        entry = SD.open(FileName);        
      } while(entry);
      layer_counter -= 100;

      do {
        layer_counter++;
        FileName = foldersel_long;
        FileName += "/";
        FileName += layer_counter;
        FileName += ".png";
        entry = SD.open(FileName);    
      } while(entry);
      layer_counter --; 

      if (layer_counter <= 1080){
        screen111();
      }else{
        screen112();
      }
      }
        break;
      case 111: {
        homing_canceled = false;
        print_paused = false;
        print_canceled = false;
        current_state = 0;
        current_layer = 0;
        Position_before_pause = 0;
        Transition_Exposure = Base_Exposure;
        screen1111();
        gfx2->fillRect(136, 52, 6, 16, 0x8410);
        gfx2->fillRect(146, 52, 6, 16, 0x8410);        
        screen1111_state();
        screen1111UP();
        delay(500);

        // -------------------------------------------------------------------------------
        // Homing Sequence
        // -------------------------------------------------------------------------------
        stepper.setCurrentPosition(0);
        stepper.setMaxSpeed(Drop_Back_Feedrate * steps_mm / 60);
        stepper.enableOutputs();
        long initial_homing = 0;
        long current_position;
        while(!digitalRead(end_stop)){
          stepper.moveTo(initial_homing);  // Set the position to move to
          initial_homing--;  // Decrease by 1 for next move if needed
          stepper.run();  // Start moving the stepper          
          current_position = stepper.currentPosition();
          if (current_position < -106799){
            stepper.disableOutputs();
            homing_canceled = true;
            gfx2->fillRoundRect(5, 5, 150, 70, 7, BLACK);
            gfx2->fillRoundRect(7, 7, 146, 66, 5, RED);
            gfx2->fillRoundRect(9, 9, 142, 62, 3, BLACK);
            gfx2->fillRoundRect(16, 11, 5, 10, 1, RED); 
            gfx2->fillCircle(18, 25, 2, RED); 
            gfx2->setTextColor(WHITE);
            gfx2->setTextSize(1);
            gfx2->setCursor(27, 23);
            gfx2->println("Homing error,");
            gfx2->setCursor(13, 41);
            gfx2->println("print canceled."); 
            gfx2->fillRoundRect(82, 51, 67, 18, 2,  0x879F);
            gfx2->setCursor(100, 64);
            gfx2->println("OK :(");
            while(digitalRead(buttonOK) == HIGH);
            break;  
          }
          if (Duration >= 500 && screen == 1111 && digitalRead(buttonOK) == LOW) {
            screen11111();
            startTime = millis();
          }
          Duration = millis()-startTime;
          if (Duration >= 500 && screen == 11111 && digitalRead(buttonOK) == LOW){
            stepper.disableOutputs();
            homing_canceled = true;
            break;
          }
          if (Duration >= 500 && screen == 11111 && digitalRead(buttonBack) == LOW){
            screen1111();
            gfx2->fillRect(136, 52, 6, 16, 0x8410);
            gfx2->fillRect(146, 52, 6, 16, 0x8410);            
            screen1111_state();
            screen1111UP();
          }
        }
        delay(50);
          
        if (homing_canceled != true){
          stepper.disableOutputs();
          stepper.setCurrentPosition(0);
          digitalWrite(FAN, HIGH);
          if (screen != 11111){
            gfx2->fillRect(136, 52, 6, 16, YELLOW);
            gfx2->fillRect(146, 52, 6, 16, YELLOW);
          }
        }
          
        // -------------------------------------------------------------------------------
        // Printing Loop
        // -------------------------------------------------------------------------------       
        while(!homing_canceled && !print_canceled){            
          estimated_seconds = 0;
          estimated_hours = 0;
          estimated_minutes = 0;
          motor_updown_time_total = 0;
          if (current_layer < Base_Layer)
            estimated_seconds += (Base_Layer - current_layer) * Base_Exposure;                
          estimated_seconds += (layer_counter - current_layer) * Regular_Exposure;            
          motor_updown_time_total += (layer_counter - current_layer - 1) * motor_updown_time;            
          estimated_seconds += motor_updown_time_total;             
          estimated_hours = estimated_seconds / 3600;
          estimated_minutes = (estimated_seconds % 3600) / 60;
                        
          print_next_png();
            
          if (screen != 11111 && screen != 11112){                
            gfx2->fillRoundRect(2, 38, 116, 40, 3, BLACK);
            gfx2->setFont(&FreeSans8pt7b);
            gfx2->setTextColor(WHITE);
            gfx2->setTextSize(1);    
            gfx2->setCursor(6, 54);
            gfx2->print(current_layer);      
            gfx2->print(" / ");
            gfx2->print(layer_counter);
            gfx2->setCursor(6, 74);
            gfx2->print(estimated_hours);
            gfx2->print("h ");
            gfx2->print(estimated_minutes);
            gfx2->print("min");
          }
          
          if (current_state != 4 && current_state != 5){
            current_state = 1;
            screen1111_state();
          }
                  
          turn_on_LED();          
          gfx1->fillScreen(BLACK);
          
          if (current_state != 4 && current_state != 5){
            current_state = 2;
            screen1111_state();
          }
          lift_print();
          delay(50);
          
          if(current_layer == layer_counter)
            break;
            
          // -----------------------------------------------------------------------------
          // Pause Handling
          // -----------------------------------------------------------------------------          
          if(print_paused == true){
            Position_before_pause = stepper.currentPosition();
            stepper.setMaxSpeed(Fast_Lift_Feedrate * steps_mm / 60);
            stepper.enableOutputs();
            if (Position_before_pause + (20 * steps_mm) <= max_height * steps_mm)
              stepper.move(20 * steps_mm);
            else
              stepper.moveTo(max_height * steps_mm);  
            while (stepper.distanceToGo()!= 0)
              stepper.run();
            stepper.disableOutputs();
            delay(10);
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

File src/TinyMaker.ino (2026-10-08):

/**
 * @file TinyMaker-Firmware-v1-0-2.ino
 * @author Tinymaker Team (Original), Viktoras Sidlauskas (Modified)
 * @version 1.0.2-vs-wifi-0.1
 * @date 2027-07-26
 * @brief Main firmware for Tinymaker MSLA 3D Printer.
 *
 * board ESP32-WROOM-32E-N4
 * Modifications by Viktoras Sidlauskas slibbinas@gmail.com
 *
 * This file handles the entire print process, UI interaction, motor control, and UV exposure logic. 
 *
 * changes
 * - Added detailed comments (EN)
 * - Removed dead code
 * - Code organization and cleanup
 * - Corrected typo: "Maintenance" of Screen 2: Main Menu
 */

 // ===================================================================================
// Build switches - set to 1/0 and recompile
// ===================================================================================
#define ENABLE_NETWORK       1   // 0 = firmware be WiFi/upload (kaip originalas)
#define ENABLE_SERIAL_DEBUG  0   // 0 = jokio Serial isvesties
#ifndef ENABLE_CRASH_TEST        // override with -DENABLE_CRASH_TEST=1 for a dev crash-pipeline test
#define ENABLE_CRASH_TEST    0   // 1 = dev-only /api/debug/crashtest forces a panic. NEVER 1 in a release.
#endif

#if ENABLE_SERIAL_DEBUG
  #define DBG    Serial.printf
  #define DBGLN(x)  Serial.println(x)
#else
  static inline void DBG(const char *, ...) {}
  #define DBGLN(x)
#endif

// Maksimalus modelio PNG failu skaicius: N x 0.05 mm auksciui.
// Originalas: 1080 (=54 mm). Pakelta iki 1200 (=60 mm) - realus sio
// spausdintuvo limitas; Z eigos atsarga kelimui lieka (max_height = 68 mm).
#define MAX_LAYER_FILES 1200

// Mask LCD (gfx1, ST7789) is 320 px wide. PNGDraw unpacks each scanline into a
// 320-wide stack buffer, but PNGdec writes getWidth() pixels and accepts up to
// 2560 - a layer image sliced for another printer (not the 320x240 TinyMaker LCD)
// overruns that buffer and crashes mid-print (0.18.3, device c6d69fcf; reproduced
// 2026-09-28). The print-start guard and PNGDraw both clamp to this.
#define MASK_LCD_WIDTH 320

#include <SPI.h>
#include <EEPROM.h>              // For storing settings persistently
#include <AccelStepper.h>        // Stepper motor control library
#include <Arduino_GFX_Library.h> // Graphics library for driving displays
#include "FreeSans8pt7b.h"       // Custom font
#include <PNGdec.h>              // PNG decoder library for reading print layers
#include <SdFat.h>               // SD card file system library
#include <esp_system.h>          // hardware random for boot-animation shuffle
#include <esp_core_dump.h>       // read the panic backtrace saved to the coredump partition
#include <esp_ota_ops.h>         // esp_ota_get_app_elf_sha256(): which build is running (crash report)
#include <esp_timer.h>           // one-shot timer that confirms a new firmware after it has run (OTA rollback)
#include "ModelImport.h"         // Shared ZIP import result/option structs

#if ENABLE_NETWORK
#include <WiFi.h>
#include <WiFiManager.h>   // tzapu, v2.0.x
#include <ESPmDNS.h>
#include <WebServer.h>
#include <unzipLIB.h>      // bitbank2
#include <Update.h>        // web /update firmware flashing
#include <ArduinoOTA.h>    // PlatformIO espota uploads
#include <esp_wifi.h>      // reliable WiFi credential erase / config read
#endif
#include <Preferences.h>   // NVS: forcePortal flag, total print hours
                           // (outside the network guard - print hours are
                           // tracked in network-free builds too)

// Resin estimation globals live in PNG.ino - forward-declare for the
// files compiled before it (Interface.ino, TinyMaker.ino)
extern double resinUsedMl;
extern double resinEstimateMl;

// --- Resin volume math (R-cal 0.17): ONE definition for the whole build ---
// One masking-LCD pixel area: 40.8 x 30.6 mm / (320 x 240) = 0.01626 mm^2 (from
// the PrusaSlicer TinyMaker profile). Volume = whitePixels * PX_AREA_MM2 *
// layerHeight (mm) -> mm^3; /1000 -> ml.
// This lived in PNG.ino, which is concatenated AFTER Network.ino - so
// estimateModelResin() carried a duplicated bare 0.01626 literal. Declared here
// (TinyMaker.ino is prepended first) every estimate site shares one formula,
// which is also the single place the R-cal factor hooks into.
#define PX_AREA_MM2 0.01626
// Resin profiles (ResinProfile.ino) - declared here because Interface.ino and
// Network.ino come before it in the .ino concatenation order.
#define RESIN_MAX_PROFILES 16
// A profile is the whole print recipe: everything that decides how the print
// comes out. What stays outside describes the MACHINE and changes nothing about
// the result - VAT size and empty weight, the low-resin warning levels, "ask
// about refill", the pause inspection lift and the screen sleep.
//
// Layer height is IN (V 08-16). Exposure without it is an incomplete recipe -
// 0.05 mm needs less light than 0.10 mm - so two profiles for one resin is the
// normal case, exactly like a slicer's "material x layer height" rows. It also
// makes the flat-print mismatch LESS likely, not more: today the printer's
// height and the slicer profile are matched by hand in two separate places,
// which is how that bug happened at all. LH-chk still checks the file itself.
struct ResinProfileValues {
  float layerHeight;   // mm - only 0.05 or 0.10 exist on this machine
  long baseExposure;   // whole seconds (EEPROM addr 2)
  long regularDs;      // deciseconds (0.17 0-3)
  uint8_t baseLayers;
  uint8_t transitionLayers;
  uint8_t slowLiftDist, fastLiftDist;      // mm
  int slowLiftFeed, fastLiftFeed, dropBackFeed;   // mm/min
  float density;       // g/ml
  float calFactor;     // R-cal slope
  float fixedMl;       // R-cal per-print offset (ml)
  // The weighed samples travel WITH the resin. They are grams measured against
  // one particular resin, so leaving them on the machine would let the next
  // weighing fit a line through two different resins - and would make the
  // dashboard call a never-weighed resin "calibrated". -1 = no sample.
  float calRawA, calGramsA, calRawB, calGramsB;
};
// Provenance travels WITH the profile, not just in the gh-pages catalogue: once
// installed, a profile still has to be able to say who tested it and where to
// buy it, otherwise the badge disappears exactly when the resin starts being
// used (V 08-16). Empty = unknown, which is the normal case for a profile the
// user saved themselves.
struct ResinProfileMeta {
  String testedBy;     // who printed with it - "" for a self-made profile
  String testedOn;     // when, free text ("2026-08")
  String buyUrl;       // affiliate/redirect link, shown only when present
};
// One read of the profile file answers everything the list needs.
struct ResinProfileInfo {
  ResinProfileValues v;
  ResinProfileMeta meta;
  String display;
  bool builtin;
  bool edited;         // a built-in whose numbers differ from the flash ones
  bool hasFile;        // an overlay file exists on the card (may equal factory)
};
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

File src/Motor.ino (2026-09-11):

/**
 * @brief Manual Lift
 * Moves the build plate up based on selected distance.
 */
void manual_lift(){
  stepper.setMaxSpeed(Drop_Back_Feedrate * steps_mm / 60);
  stepper.enableOutputs();
  switch (screen){
    case 2211:
    stepper.move(0.1 * steps_mm);
      break;
    case 2221:
    stepper.move(1 * steps_mm);
      break;
    case 2231:
    stepper.move(10 * steps_mm);
      break;    
  }
  /* Jog ceiling (0.17). Past the mechanical top the ULN2003 silently drops steps
     while the counter keeps counting, so the plate ends up lower than the number
     says and nothing on screen admits it.
     Clamping is only correct when the zero is REAL: without homing, zero is
     wherever the carriage happened to stand when the printer booted, and a limit
     measured from it would mean anything - worst case it would refuse to lift a
     plate that is actually sitting at the bottom. Unhomed therefore keeps the old
     behaviour (it moves), and the height already reads "not homed" there.
     The second guard is for a plate that is somehow ALREADY above the ceiling:
     a bare moveTo(ceiling) would drive it DOWN, so an Up press would move the
     plate the wrong way. Target the current position instead - the jog simply
     does nothing rather than surprising anyone. */
  bool atTop = false;
  if (zHomed) {
    const long ceilingSteps = (long)(max_height * steps_mm);
    if (stepper.targetPosition() > ceilingSteps) {
      const long here = stepper.currentPosition();
      stepper.moveTo(here > ceilingSteps ? here : ceilingSteps);
      // Clamped to nothing: say so. Right after a print the plate IS at the
      // ceiling, so this is the normal case, not an edge one - and a jog that
      // silently does nothing reads as a broken button (audit 09-05).
      atTop = (stepper.distanceToGo() == 0);
    }
  }
  byte cancel = 0;
  while (cancel == 0 && stepper.distanceToGo()!= 0){
    stepper.run(); 
    if (digitalRead(buttonBack) == LOW)
      cancel = 1;       
  }
  stepper.disableOutputs();  
  if (atTop) screenPlateNote("Plate is at the top");
  // The move screen is repainted for BOTH exits that leave something on screen:
  // a cancel (the Back press) and the at-top notice above.
  if (cancel == 1 || atTop){
    switch (screen){
      case 2211:
      screen221();
        break;
      case 2221:
      screen221();
      screen222();
        break;
      case 2231:
      screen221();
      screen223();
        break;    
    }  
  }
}
////////////////////////////////////////////////////////////////////////////////////////////////////////////////////////
////////////////////////////////////////////////////////////////////////////////////////////////////////////////////////
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

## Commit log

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2026-07-08 v0.7.1: fix live resin counter during printing, tolerate 'v' prefix in version check, cancelable resin estimate, cached version check, small cleanups
    - Fix: live resin (ml) counter vanished after the first layer - the per-layer
    status redraw overwrote the line without it; now redrawn each layer (and the
    time format matches the initial screen: "1h4m 6.2ml")
    - Fix: a leading "v" in version.txt (e.g. copied from a git tag) parsed as
    0.0.0 and silently reported "Up to date"; cmpSemver now skips it
    - Resin estimation can now be canceled with Back mid-scan
    - Update screen caches a successful version check for 5 min instead of
    re-blocking the UI ~6 s on every visit
    - Cleanup: removed a no-o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
    [Interface.ino, Network.ino, PNG.ino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]
2026-07-08 v0.8.0: SD-card import, print-hours counter, unified screen UI, action-hint buttons, responsive estimate cancel, update-page gate fix
    New features
    - Import from SD: .sl1/.zip archives copied to the SD root appear in the
    Print list (blue); OK converts them with the existing unpack pipeline
    (moved to Import.ino, works with ENABLE_NETWORK=0), archive deleted after
    success, partial folders cleaned up on failure. Long-press deletes the
    archive without importing.
    - Lifetime print-hours counter on the About screen, persisted in NVS
    (survives re-flash); written only at print end/cancel to spare flash.
    UI
    - Shared UI helpers (uiFrame/uiTitle/uiButton/uiButtons/uiActionHint) -
    frames, tit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
    [Folder.ino, Import.ino, Interface.ino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]
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2026-07-09 v0.8.4: System gear icon as a pixel-exact bitmap
    The gear is now a 27x27 1-bit bitmap drawn with drawBitmap(ORANGE) -
    8 identical teeth, rounded N/S/W/E tips, large center hole (shape
    iterated with the maintainer). Replaces the primitive-drawn gear.
    [Interface.ino]
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2026-07-09 v0.10.0: reboot prompt after WiFi toggle + full-width Save button (PR #2 follow-ups)
    - LCD: toggling WiFi in System > Advanced now opens a 'Reboot required.
    Reboot now?' prompt (screen 442) - OK reboots, Back applies on next boot
    (network stack has no runtime teardown/bring-up path).
    - Web: saving config with WiFi unchecked reboots the printer after the
    response is sent; confirm dialog text now says so.
    - Web: Save config button spans the full form width (was one grid column).
    - Version bump to 0.10.0.
    [Interface.ino, Network.ino, TinyMaker.ino]
2026-07-10 v0.12.0: Web control off = view-only dashboard (was: no web at all)
    Turning Web control off no longer stops the HTTP server. The dashboard
    stays open for anyone to watch (status, layers, resin left, SD contents),
    but every state-changing action returns 403 and the UI disables itself
    with a "view only" banner:
    - blocked: print start/pause/resume/stop, SD delete, config save/defaults/
    mqtt-defaults/dry-run, VAT refilled, firmware install/upload
    (rejectIfWebControlOff guard on the API handlers + otaWebAllowed)
    - still working: dashboard viewing and status polling, model details,
    PrusaSlicer/UVtools model upload (as before PR #2), MQTT/Home Assistant
    - WiFi off is unchanged: everything ne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
    [Network.ino]
2026-07-10 v0.12.2: Ask refill before print, resin used/total display, 1-3 ml threshold
    - "Ask refill" (default On, System > Advanced item 6 / dashboard Settings):
    every print starts with a "VAT refilled?" question - LCD screen 115
    (OK = yes, restart estimate from full; Back = no, keep counting) and a
    browser dialog on web starts. Keeps the bookkeeping honest for users
    who forget the VAT refilled button; tidy users turn it off.
    - Low-resin warning (114) gains UP = "Refilled" shortcut (top-right hint):
    mark full and re-run the start checks.
    - Fresh model estimates now live in resinNeedForModelMl (set by the resin
    screen, cleared on a new preview) instead of piggybacking on the
    startFromRes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
    [Interface.ino, Network.ino, TinyMaker.ino]
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2026-07-10 v0.13.2: fast SD list with pagination and filter
    - /api/files no longer computes folder sizes (sdFolderSize walked every
    layer file of every model - O(models x layers), seconds with a full
    card; the helper is gone). Archives keep their cheap file size.
    - Dashboard SD manager: client-side pagination (12 per page, Prev/Next)
    and a filter box that appears when the list outgrows one page.
    [Network.ino]
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2026-07-11 feat: heap & uptime instrumentation - the 1.0.0 stability yardstick
    /api/status gains freeHeap, minFreeHeap (lowest since boot - leak
    detector), maxAllocHeap (largest block - fragmentation indicator) and
    uptimeSecs. The dashboard status card shows them as a small grey debug
    line ("heap 142k · min 89k · blk 96k · up 2d 4h"). MQTT publishes
    min_free_heap with HA discovery (diagnostic category) so Home Assistant
    can graph soak tests.
    [Network.ino]
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2026-07-12 feat: 0.14.1 - beta findings round (exposure dots & proportional ladder, WiFi bars, runtime flip fix, manual themes, beta channel pointer, ROADMAP)
    Exposure test: bars now carry their number as holes (1 dot = shortest) so
    a peeled strip stays identifiable however it is flipped - the first real
    strip proved the vat view mirrors. Ladder is proportional (40-160% of
    Regular, bar 5 = current setting) instead of fixed +-seconds, which
    saturated on fast resins. Result screen reads "Dots 1..8 = X..Ys".
    WiFi Info screen shows the same green strength bars as the main menu.
    Dashboard: running time has a single writer now - the local ticker with
    a unified fmtDur() (h rollover); the server text only se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
    [Interface.ino, Network.ino]
2026-07-12 fix: 0.14.2 - status messages hidden in Settings/Update views
    The single #statusMsg toast lived inside #homeView, which openView()
    hides whenever a non-home tab is active. So every msg() in the Settings
    and Update views (Config saved, Backup to SD, MQTT/defaults reset, ...)
    wrote to a hidden element and appeared to do nothing - most visibly
    "Backup to SD", which has no other UI side effect. Move #statusMsg above
    the view containers so feedback shows in every tab; #statusMsg:empty
    collapses it when idle.
    [Network.ino]
2026-07-12 feat: Restore from SD button on the dashboard [experimental]
    Adds POST /api/config/restore/sd and a "Restore from SD" button next to
    "Restore from file". Applies tinymaker-backup.json from the SD card - the
    same file the first-boot prompt offers after a full USB reflash - so a
    user can restore settings without keeping the file on a computer. Same
    web-control/busy gating and wifi-off reboot path as the file restore.
    [Network.ino]
2026-07-12 feat: inline setup steps for Telegram (BotFather / chat id) [experimental]
    loadConfig overwrote the token hint, dropping the setup guidance. Split
    it: tgHint keeps the short "what it does" line, and a numbered list walks
    the user through BotFather -> token, Start the bot, @userinfobot -> chat
    id (with @RawDataBot for groups), Save + Send test. No external links -
    self-contained, ASCII only.
    [Network.ino]
2026-07-12 feat: show git commit build tag next to the version [experimental]
    Experimental builds all report the same SemVer (0.14.2), so there was no
    way to tell from the dashboard which build is flashed. A pre-build script
    injects -DGIT_REV (short commit hash, +dirty for uncommitted tracked
    changes); the header now shows "Firmware 0.14.2 (<hash>)" in a separate
    span. FIRMWARE_VERSION stays clean for OTA/self-update comparisons, and
    the fwVersion span (used for reload-on-change) is untouched.
    [Network.ino]
2026-07-12 fix: show the update overlay immediately after confirming [experimental]
    The "Updating firmware" overlay only appeared after the upload/download
    finished, leaving a blank several-second gap right after the confirm
    closed (more noticeable now that the modal is non-blocking). Show the
    overlay as soon as the user confirms; hide it again on a real error. On
    an install timeout the overlay stays - the printer is likely mid-flash
    and unable to answer; the existing 90s watchdog clears it otherwise.
    [Network.ino]
2026-07-12 fix: Connect tab shows only when Connect is enabled; settings back in Settings
    Revert the Connect-settings move (657385a) - the real UX gap was the
    always-visible Connect tab dead-ending on a lone unchecked "Enable" box.
    The settings return to the main Settings form (single form, original
    hasArg semantics restored, /api/config/connect endpoint dropped) and the
    Connect toolbar tab now appears only while "Enable TinyMaker Connect" is
    on, hidden otherwise (and kicks back to Dashboard if it goes off while
    open). "Connect settings" still jumps to Settings with the section
    expanded and scrolled into view.
    [Network.ino]
2026-07-12 fix: Telegram help + test buttons share a row; Save config gets breathing room
    The help and Send-test buttons stack into the existing .actions two-column
    grid, and both Save config buttons get a margin so they no longer stick
    to the fields above.
    [Network.ino]
2026-07-12 fix: Connect review follow-ups - busy gate on test, token withheld view-only
    Two items left open from the PR #7 review:
    - /api/connect/test is a blocking TLS request (up to 8 s); gate it on
    printerBusy() so it can never stall a print's narrow network windows.
    - connectPublishToken was returned by GET /api/config even when Web
    control is off; a view-only dashboard now gets an empty token
    (connectTokenSet still reports it exists) - same rule as the MQTT
    password and the Telegram bot token.
    [TinyMakerConnect.ino]
2026-07-12 fix(boot-anim): harden playback + install, use uiConfirm for delete
    Addresses review findings on PR #9:
    - playBootAnimFromSd: cap boot playback at 250 frames / 10 s and allow
    Back to skip, so a corrupt or oversized frameCount (untrusted, uint16)
    can no longer hold boot hostage at ~25 KB/frame SD reads.
    - handleApiBootAnimInstall: accumulate the header until the full 12 bytes
    arrive (or timeout) before the TMB1 magic check, instead of breaking
    after the first read — a slow server split across small segments no
    longer false-rejects a valid file.
    - handleApiBootAnimInstall: cap the download at 8 MB and delete the
    partial file on overflow, so a bad/chunked URL can not fill the SD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
    [Interface.ino, Network.ino]
2026-07-12 fix: toast appears next to the click, not at the viewport top [experimental]
    Live feedback: pressing a button at the bottom of a long page put the
    toast out of sight at the top. Track the last pointerdown Y and anchor
    the toast just below it (clamped to the viewport); with no pointer yet
    (e.g. poll errors at load) it falls back to top-center.
    [Network.ino]
2026-07-13 fix: systemic button top-margin; update overlay clears promptly [experimental]
    - Buttons kept sticking to the content above them (Save, Upload model, ...)
    because only .secondary carried a top margin; primary buttons had none.
    Move margin-top:10px onto the base button rule and zero it inside the
    row/grid containers (.grid/.actions/.connectActions/.rowActions) that own
    their own spacing - one rule instead of per-button inline fixes.
    - refreshStatus uses a 4s (not 30s) status timeout while the update overlay
    is up: a poll hung on the pre-reboot connection was blocking the
    auto-reload via statusInFlight, so the spinner lingered ~10s+ after the
    printer was already back; now it relo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
    [Network.ino]
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2026-07-14 fix: delete-feedback toast + fixed desktop dashboard layout
    Deleting a large model blocks the printer for tens of seconds - the dashboard
    now keeps a 'Deleting...' toast up (and silences status-poll timeout toasts)
    until the call returns, with a 3-minute request timeout. Desktop home layout
    stops auto-flowing cards: status/controls/3D stack in the left column, the SD
    manager owns the right column full-height (cards used to land next to the
    wrong neighbours mid-print). 3D canvas colors follow the theme.
    [Network.ino]
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2026-07-14 ui: settings desktop layout rework + connection robustness
    Settings desktop layout: Print settings as a full-width 4x4 grid, Network |
    Phone notifications side by side (notifications split into its own card),
    Boot animation stacked under notifications, Backup & restore full width with
    the four actions in one row. Settings now spans the same width as the tab row.
    Connection fixes for flaky dashboard actions (Failed to fetch):
    - WiFi.setSleep(false): modem sleep delayed first requests by seconds and
    dropped the multicast packets mDNS needs - tinymaker.local died minutes
    after boot.
    - api() retries once on a transport error: the browser reuses keep-alive
    sockets the printer already close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
    [Network.ino]
2026-07-14 feat: boot-animation Save/Show and default library from project pages
    Boot animation card rework (user request):
    - Picking an animation is now staged and applied with the card's own Save
    config button, matching how the other settings cards behave.
    - New Show button plays the animation on the printer's screen right away
    (POST /api/boot-anim/preview: idle-gated, reply sent before playback so the
    browser call does not time out; returns to the main screen after).
    - Default library: bunny, resin-drip and malfunction .tmb files live on
    gh-pages next to the self-update channel; the card lists the ones missing
    from the SD card with an Install button (existing install endpoint).
    Community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
    [Interface.ino, Network.ino]
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2026-07-14 fix: boot-anim install no longer auto-selects the downloaded animation
    Selection is an explicit act now (pick + Save config, or the printer menu);
    install silently overriding the active choice contradicted that.
    [Network.ino]
2026-07-14 fix: boot-anim Save config button feedback
    The 2s status poll re-enables every #configForm button, so the Save button
    looked active with nothing staged and clicking it did nothing silently.
    setConfigDisabled now owns its state (same pattern as restoreSdButton), and a
    click with nothing staged answers with a snackbar instead of silence.
    [Network.ino]
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2026-07-14 fix: 3D progress 0% boundary + archive preview display priority
    - drawIso painted the whole first slice solid at 0% (t<=doneFrac with
    doneFrac=0) - a flat-lying model showed a big orange pancake before the
    print even started. Solid now requires doneFrac>0.
    - The saved-preview GET (no type) now serves the archive/slicer render
    (preview.png) first and falls back to the canvas caches - pressing
    Preview 3D used to shadow the pretty slicer thumbnail permanently.
    [Network.ino]
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2026-07-14 fix: no auto slice-render in details, single slice run at a time
    Auto-rendering the voxel preview on every details open stacked slice-fetch
    loops when browsing between models and starved the printer - status polls
    and the details request itself timed out. Preview is back to on-demand (the
    button just stays enabled when no cache exists), and fetchSlices runs are
    sequenced: a newer run supersedes the previous one.
    [Network.ino]
2026-07-14 ui: model details action row appears once, in its final state
    Buttons used to toggle one by one as the details response landed (Calculate
    ml popping in and out, Share appearing late) - the row danced on every open.
    The whole action row now stays hidden while details load and is revealed in
    one shot with every button already in its final state; on errors it still
    appears so Back stays reachable.
    [Network.ino]
2026-07-14 ui: details preview block always visible + quick resin estimate
    - The preview area now always shows the build-volume box (empty until a
    render lands) - reserved space, no layout jumps; error paths draw the
    empty box back instead of collapsing the block.
    - Rendering the preview yields a free byproduct: a quick resin estimate from
    the sampled slices (mean white area x plate area x height), shown as
    '~X ml (quick)' until the exact printer-side Calculate ml is run.
    [Network.ino]
2026-07-14 ui: buttonless model details - preview and resin estimate load themselves
    Details redesign (user decision): Preview 3D and Calculate ml buttons are
    gone. Opening a model shows every parameter immediately, the always-visible
    build-volume box paints its own 'Loading preview NN%' progress, and Resin
    needed reads 'Estimating...' until the quick slice-based estimate lands
    (~X ml). Clicking the ~value offers the exact printer-side scan. Leaving the
    view (or opening another model) supersedes the in-flight slice run, so
    nothing keeps loading behind other views.
    [Network.ino]
2026-07-14 ui: big centered preview-progress text + estimate from restored slices
    Progress text was 15px on a 720px-wide canvas scaled down in the page - near
    invisible. Now bold 28px brand-orange, centered. Slices restored from the
    older localStorage format carry no mlEst - derive it from the slices in hand
    so 'Estimating...' always resolves.
    [Network.ino]
2026-07-14 fix: opening a model cancels the previous slice run immediately
    The previous model's slice fetch monopolized the printer, so the newly
    opened model's details request queued behind it and the parameters sat
    empty until it finished. The supersede bump now happens at details-open,
    not only when the new slice run starts.
    [Network.ino]
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2026-07-14 ui: status-poll toast only after 3 consecutive failures
    A single missed 2s poll is routine while the printer does SD-heavy work
    (directory scans, slice streaming) and self-recovers - the toast only
    appears when polls keep failing for ~6s.
    [Network.ino]
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2026-07-14 fix: redraw OTA/upload progress 4x less often
    Drawing to the display while flash/SD writes run corrupts SPI transfers -
    orange streaks flash across the screen (user finding). Fewer redraws, fewer
    corrupted pixels; the bar itself only fills incrementally anyway.
    [Network.ino]
2026-07-14 feat: model preview lives in the dashboard 3D card (idea A)
    The SD row's Details button becomes Preview: it renders the model straight
    into the Print progress 3D card (retitled 'Model preview' while idle) with
    the usual %/bar progress, a compact info line (layers/height/time/resin -
    quick estimate as a render byproduct) and a Share button. The print takes
    the card over automatically (title flips back, info hides); deleting the
    shown model clears it. The details view stays intact as Brian's Connect
    deep-link target (window.modelDetails), so this is trivially revertable.
    Shared pipeline extracted: renderVoxelPreview(cv,...) + loadSavedPreviewTo.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
    [Network.ino]
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2026-07-14 ui: Connect auto-backup becomes a settings checkbox
    Brian's Enable/Disable button in the Backup pane broke the pattern twice: a
    setting acting as an instant button, living away from the other Connect
    settings. It is now a checkbox in Network > TinyMaker Connect (saved with
    Save config like everything else, enable/disable confirm kept); the Backup
    pane keeps only real actions. Also: opening the page directly on #connect
    raced the config fetch and left the hosted-app stub - updateConnectView now
    retries once the registration state is known.
    [Network.ino]
2026-07-14 fix: refuse config posts until settings load + bump to 0.15.0
    An unloaded form serializes every checkbox as OFF; posting it once wiped
    the printer's settings during a connectivity hiccup (user incident,
    2026-07-14). configFormData - the single path for all 9 form posts - now
    throws a readable error until /api/config has populated the form.
    [Network.ino]
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2026-07-14 fix: wake a blanked display before the boot-anim Show playback
    handleApiBootAnimPreview drew straight onto a displayOff() screen when the
    UI timeout had blanked it, so Show appeared to do nothing.
    [Network.ino]
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2026-07-14 feat: Model preview card is always on the dashboard
    The card no longer hides: idle shows a pick-a-model placeholder, the last
    previewed model is remembered (localStorage) and restored from the saved
    preview cache on page load (never a full slice render), a print started on
    the printer replaces a stale idle preview with a note, and deleting the
    previewed model returns the placeholder.
    [Network.ino]
2026-07-14 feat: PWA manifest + home-screen icon (backlog #20)
    /manifest.json (standalone, dark theme) and a 1.8 KB 192px PROGMEM icon at
    /pwa-icon-192.png, linked from the dashboard head together with theme-color
    and the apple-* standalone tags. On plain-HTTP LAN this yields an Add to
    Home screen shortcut with the project icon (Android) and a fullscreen
    standalone launch (iOS) - the no-TLS 90% of a native app.
    [Network.ino, PwaIcon.ino]
2026-07-14 fix: upload indicator switches to Unpacking on the printer... once bytes are sent
    uploadWithProgress kept painting Uploading 100% with a growing timer while
    the ESP unpacked the archive (minutes for big models) - it looked hung. An
    xhr.upload.onload flag now switches the text to an unpacking note with its
    own timer; benefits the SD manager upload and hosted Connect Import alike.
    [Network.ino]
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2026-07-15 fix: review fixes - Connect retry backoff, early cancel notify, upload cap + feedback intake
    - Connect sync retries back off exponentially (30s..30min) and give up
    after 8 failures instead of stuttering the printer 8s/30s forever;
    the give-up lands in connectLastStatus.
    - The canceled phone notification fires before the final lift (decision
    is final, run time known) and now includes the run time; a cancel
    pressed during the lift is still caught at the exit point.
    - uploadWithProgress gets a 10-minute whole-request cap with a clear error.
    - Feedback intake: dashboard header Feedback link (fw/build auto-attached
    via query), docs/feedback form page for gh-pages, and a paste-in
    Cloud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
    [Network.ino, TinyMaker.ino, TinyMakerConnect.ino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]
2026-07-15 feat: power-loss print resume from an SD checkpoint file
    While printing, a tiny fixed-width record (/tinymaker-resume.txt) is
    rewritten in place at safe moments - after each lower (exact position),
    before each peel lift (lowest-bound position) and at pause parking -
    and deleted at the print's single exit point. On boot a valid record
    brings up a new Resume/Discard prompt (screen 427).
    Resume deliberately skips homing (the half-printed object would hit the
    vat before the endstop): the checkpointed stepper position is re-trusted
    (the geared Z stepper is self-locking), the last - possibly FEP-stuck -
    layer is peeled free, and the plate settles at the next layer height.
    Mid-move checkpoints alw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
    [Interface.ino, Network.ino, Resume.ino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]
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2026-07-15 fix: cache failed version checks - a slow GitHub froze the whole printer
    otaCheckLatest only cached successful checks, so once a check failed every
    GET /api/update re-ran the blocking TLS call (6 s connect + 6 s read). On a
    single-threaded ESP that stalls the web server and the LCD alike - the
    printer answered ping but not HTTP for tens of seconds, which is exactly the
    symptom seen while testing tonight. Failures now cache for 60 s.
    [Network.ino]
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
